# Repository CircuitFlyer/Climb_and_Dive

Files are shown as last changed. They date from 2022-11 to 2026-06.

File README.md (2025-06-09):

# Climb_and_Dive

## An Open Source Advanced Control Line Timer Project

Climb and Dive is an open source DIY project to create your own advanced timer for an electric powered control line model aircraft.  How advanced?  How about an active, governor timer with wireless programming!  Utilizing an inexpensive microcontroller development board in conjunction with an add-on circuitboard the timer is compact, light-weight and very simple to make and use.   Without opening any hatches or disconnecting any plugs the timer can be quickly programmed at the flying field using a Bluetooth application on your smartphone.  Because it’s open source, you can customize the functionality to your liking or even add new features.

## Project Philosophy

This project is a progression of the original basic Touch and Go timer.  I wanted to combine all of the positive features of other timers into one compact unit.  The target user group for this timer is first time beginners to novice flyers all the way up to more advanced stunt flyers.  It's still intended to adhere to the basic KISS principle; minimal components, built-in safety features and simple to make and operate without overly complex programming requirements.  I also wanted it to be easy as possible to change settings at the field without having to purchase or use any other attachments.

## Instructions

All of the assembly, programming and operating instructions can be found in the instruction manual on the document pages, [www.circuitflyer.com](https://circuitflyer.com/Climb_and_Dive/)  The program files can be downloaded from within the web pages or from the release tab above.

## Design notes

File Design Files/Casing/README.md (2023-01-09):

---
nav_exclude: true
---

# 3D Printed Enclosure for the Climb_and_Dive timer

Download the .stl files above to print a casing to house a complete timer assembly.  The casing is not completely weather tight but should add a layer of protection.

Assemble the top and bottom using (4) M2 x 10 machine screws.

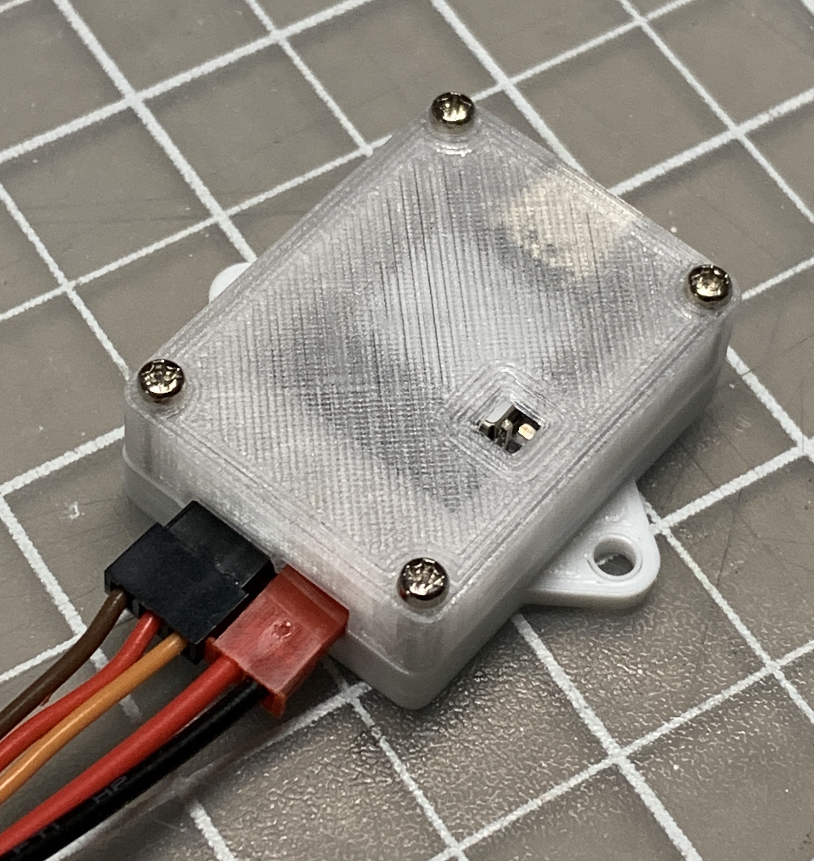
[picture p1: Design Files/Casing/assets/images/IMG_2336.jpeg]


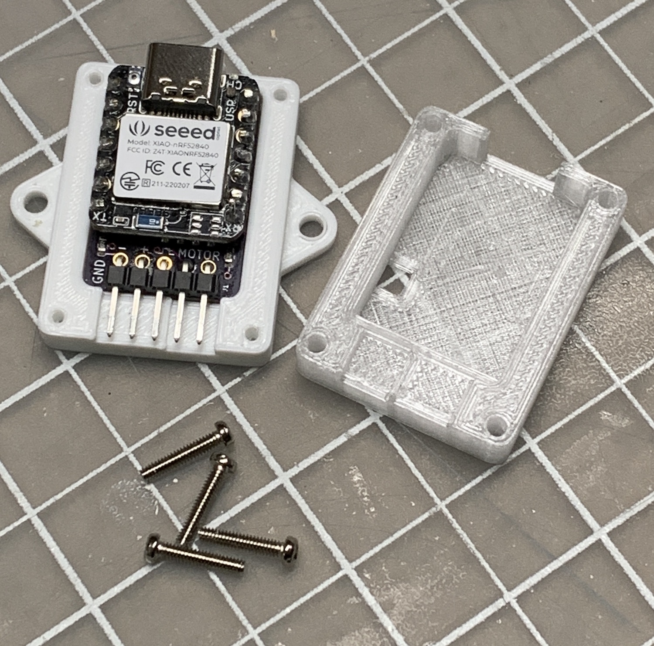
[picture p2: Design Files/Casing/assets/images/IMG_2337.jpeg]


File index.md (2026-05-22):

---
title: Home
layout: home
nav_order: 1
---

{% include Header.html %}
<br>
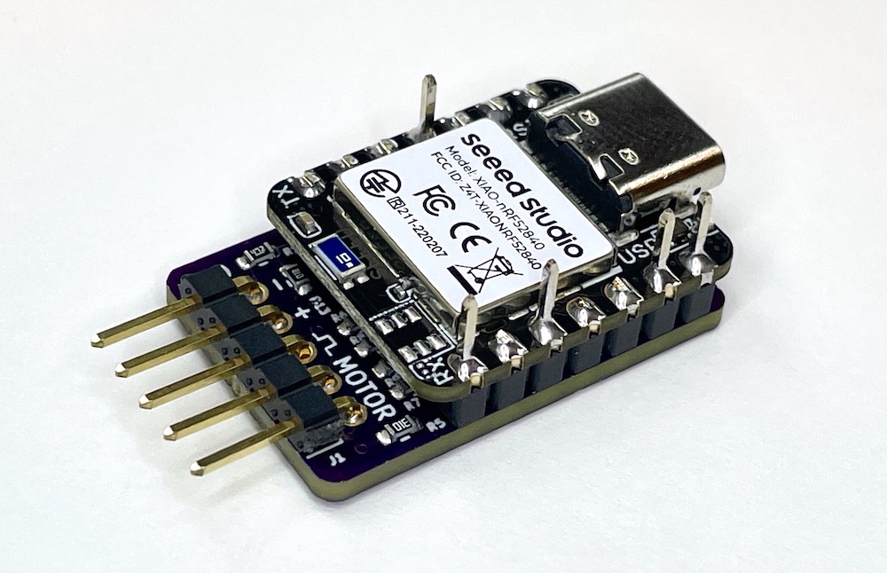
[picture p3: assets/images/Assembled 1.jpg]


# Revolutionary Active Control for Electric Control Line Flying!
{: .text-center }

## What It Is
Climb_and_Dive is an open-source, do-it-yourself project that lets you build an advanced timer for electric-powered control line model aircraft. The Climb_and_Dive timer isn't just a simple switch - it's an intelligent flight control system that **actively monitors and responds** to your aircraft's flight conditions in real-time. This compact timer combines a low-cost microcontroller development board with a custom add-on circuit board to deliver professional features in a simple, user-friendly package.

## Unique Capabilities
The Climb_and_Dive timer stands out as both an **active timer** and a **governing timer** in one device. What makes it truly innovative is its **wireless programming capability** through Bluetooth and your smartphone. This eliminates the hassle of opening hatches, dealing with connectors, or using separate programming boxes.

The program code includes **built-in safety features** that provide an additional layer of protection for your power system, helping prevent damage if something unexpected occurs during operation.

Since it's open source, you have complete freedom to customize the functionality or add new features to suit your specific needs.

## Simple Assembly
The timer comes as a DIY kit that requires minimal assembly—just soldering some header pins. The kit includes two main components:

- **Seeed Studio Xiao NRF52840 development board** (the main microcontroller)
- **Custom backpack circuit board** (contains the accelerometer and RPM signal conditioning circuitry)

The backpack design streamlines wiring and makes assembly fast and straightforward.

### GREAT NEWS! **- I now also offer an easy to install remote mounted user interface.  Add a remote pushbutton start switch and a super-bright status indicator LED to your timer.  Check out all the details <a href="https://circuitflyer.com/Control_Panel/" target="_blank" rel="noopener noreferrer">HERE </a>**

## Easy Programming and Updates
Programming the microcontroller is incredibly simple—just drag and drop a few files on your computer. The microcontroller comes pre-programmed and tested, so you can start using it immediately.

As new features are released, you can easily [update your timer's code](docs/Software#software-installation) using the same simple drag-and-drop process, ensuring your device stays current with the latest improvements and capabilities.
<br> <br>

<span class="fs-6">
[Click Here to order a **Climb_and_Dive** kit on **Lectronz**](https://lectronz.com/products/climb_and_dive){: .btn .btn-green}
</span>

## Extensive List of Features ##

- Dimensions: 27mm x 18mm x 9mm.  Weight: 5g.  Ideal for mounting on the side of a profile fuselage.

- An onboard accelerometer provides a programmable automatic boost in power during a climb as well as a seperate programmable decrease in power while in a dive.

- RPM throughout the flight is actively monitored and controlled by sensing the motor voltage using a feedback control loop.  No need for a tachometer.  No guesswork.  The RPM you set is the RPM you get.

- Works with lower cost ESC’s.  The governing function takes place in the timer so expensive governing ESC’s are not required.

- Wireless programming in the field via a *free* Bluetooth app using a laptop, tablet or smart phone. The start-up delay, flight time and governed RPM settings plus a lot more can be changed without any extra tools, cards or programming boxes.

- Touch sensitive pin for user input.  No additional switches or buttons to wire and mount.  If desired, the program code does provide for an optional remote push-button switch.

- Onboard multicolour LED to indicate the status of the timer.

- Functionality to add an optional remote mounted super bright Neopixel LED so the pilot can monitor the status indicator from the centre of the circle.

- The ability to improve overhead line tension by increasing the motor RPM only when flying high overhead.

- Programmable extra RPM boost in the bottom sharp corners of stunt maneuvers.

- Innovative pilot operated **emergency stop feature**.  3 quick pulls on the control handle will stop the flight so you can safely land the airplane at any time.

- Programmable soft start.  The RPM increases over a programmable time period for smoother take-offs.

- A 3 second boost in RPM at the conclusion of a flight to improve the landing glide or as a warning to indicate the impending end of the flight.

- Following a simple programming & calibration procedure the timer can be mounted in any orientation in the airplane.

- Power to the motor is cut off quickly and automatically if the propeller inadvertently strikes the ground.  No more burned out motors or ESC’s from a crash or nose-over on takeoff.

- Auto shutdown with a loss of power or a loss of motor RPM signal.

- Auto shutdown if motor fails to reach programmed RPM on takeoff.

- Should an auto shutdown occur, the onboard LED will flash a sequence of fault codes to aid in troubleshooting.

- Built-in micro USB C port.  Plug it into your computer and it shows up as a small disk drive.   This makes it very easy to keep the software up to date with the latest revisions.

- The program code is written in Adafruit CircuitPython.  CircuitPython is an easy to read and easy to learn language well supported by comprehensive [learning guides on the Adafruit website][1].

- Reprogrammable.  Have another project idea in mind?  The Xiao line of development boards have the same footprint and pinouts as the Adafruit QTPy size of boards.  The Climb_and_Dive hardware platform is also a great starting point to use in developing code for your own project.  The Xiao can also be programmed as an [Arduino device][2] if you prefer.

<style>
  .responsive-iframe {
    width: 100%;            /* Fill the width of its container */
    max-width: 800px;       /* Optional: stop it from getting too big */
    aspect-ratio: 4 / 3;   /* Keeps it in desired format */
    border: none;
  }
</style>

<iframe class="responsive-iframe" src="https://www.google.com/maps/d/u/1/embed?mid=1vEqo7SIi-lv9DnAQE8pMjQOn-hjqEW4&ehbc=2E312F&noprof=1"></iframe>

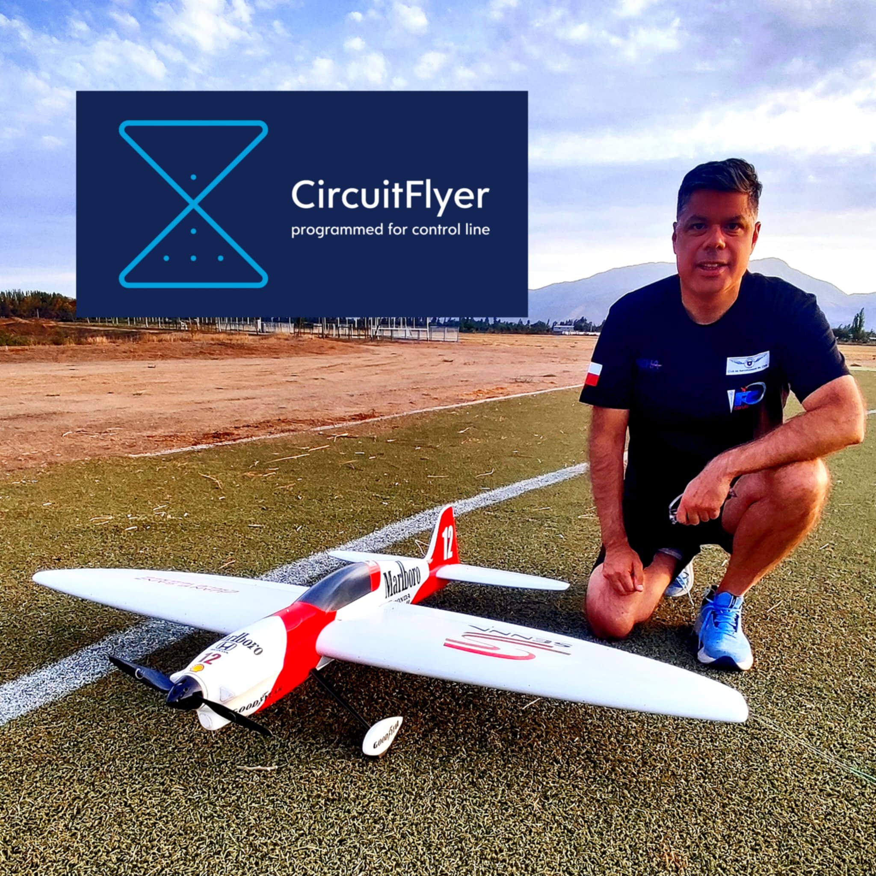
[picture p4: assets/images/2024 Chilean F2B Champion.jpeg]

Congratulations to Juan Francisco Sainz Valencia, 2024 & 2025 Chilean F2B Champion and Climb_and_Dive timer advocate.

[1]: https://learn.adafruit.com/
[2]: https://wiki.seeedstudio.com/XIAO_BLE/

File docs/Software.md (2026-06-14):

---
title: Software
layout: default
nav_order: 4
---

{% include Header.html %}

## Software Installation ##

One of the great features of the Climb_and_Dive timer is the ability to update the program code as new features and improvements become available.

**Note:** All Xiao NRF52840 microcontroller boards supplied through the Lectronz shop are shipped ready to assemble with the latest timer program already installed and tested.  Software installation is not required and you can skip ahead to the Bluetooth app installation.

The instructions below cover two separate procedures.  The first procedure is used for a quick update to the existing program code when a newer version is released.  The second procedure is used for a more in-depth update or if you purchased a blank Xiao microcontroller board from another source.

{: .highlight}
Be sure to check here from time to time to make sure you are using the most up to date version of the program code.  **Latest Version: v1.5.3**  Note: if upgrading from a previous version it is always a good idea to update both **code.py** AND the **lib** folder (Step 6 below).  See the **README** included in the download for details.

<span class="fs-6">
[Click Here to download the latest program code .zip file](https://github.com/CircuitFlyer/Climb_and_Dive/archive/v1.5.3.zip){: .btn .btn-blue }
</span>

The current version installed on your timer is shown in the name of the device that appears when you connect to it via the Bluetooth app.

### Quick Update of the Software: ###

If there is a newer release of the program code, use the following procedure to overwrite and replace only the one file called **code.py** on your timer.  (Occasionally, additional files may also need to be updated.  See the README included in the download for details.)

First, a bit of background on how CircuitPython works: Whenever the timer is powered up, CircuitPython looks for a file called **code.py**, loads it into the memory and automatically begins to run the program.  The file name must be **code.py**.  Do not rename the file for or use any other file name for the program code.  This may cause confusion as both the previous version and the newest version will have the same file name.  Hence the requirement to overwrite and replace the old version with the new version, do **not** keep both.

**Step 1** - Download the .zip file from the link above.  Unzip the download and have a look inside.  You will see several different items listed there.  You are only interested in the file named **code** that has a file extension of **.py** (the python programming language file type).

**Step 2** - Connect the timer to your computer using a USB type C cable.  The timer will power up and a new removable drive called `CIRCUITPY` will appear on your computer.

{: .highlight }
A quick note about USB C cables: If you have trouble getting the disk drive to show up on your computer there is a possibility you are not using a data cable.  There may be some USB cables that are used for charging only and are not data transfer cables.  Be sure you have the right one.

**Step 3** - Drag and drop the **code.py** file from the latest download onto the `CIRCUITPY drive`. Your computer will tell you that a file with the same name is already on the drive and ask if you want to replace the file or keep both. Click **Replace**, do **not** keep both.



Give it a second while the latest version of the program code overwrites the old file.  The timer will re-start and automatically begin running the new code.  That’s it, you’re all done.  

**Step 4** - Eject the `CIRCUITPY` drive and unplug the USB cable from the timer

### In-depth Update and New Installation of CircuitPython: ###

There are two reasons why you would need to use the following procedure:

1) If you purchased a blank Xiao NRF52840 from another source you will have to perform a new installation of CircuitPython along with all of the program files and libraries.

2) Adafruit has released a new and improved version of CircuitPython. Eventually there will be a requirement to perform a more in-depth update to use the latest CircuitPython and overwrite all of the program files and libraries on your timer with the newest versions.

**Step 1** - Download the .zip file from the link above.  Unzip the download and have a look inside.  You will see several different items listed there.

**Step 2** - Connect the timer to your computer using a USB type C cable.  If you have a new blank Xiao NRF52840, nothing will happen. Don't worry, that's normal for a board that doesn't have CircuitPython installed yet.  If you are updating your existing timer a new removable drive called `CIRCUITPY` will appear on your computer.

**Step 3** - Enter Bootloader mode<br>

Before we install CircuitPython to the Seeed Studio XIAO nRF52840, it needs to be in bootloader mode. Enter the bootloader mode by clicking the very tiny Reset Button **twice**:

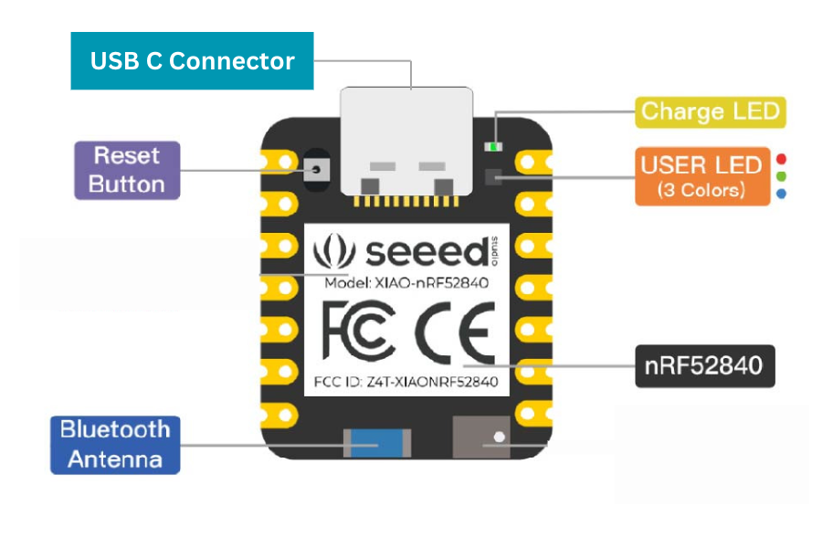
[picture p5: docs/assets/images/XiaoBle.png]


Give it a couple of seconds, then the `XAIO-SENSE` disk drive will show up:



**Step 4** - Drag the **CircuitPython .uf2** file that you downloaded and drop it onto the `XAIO-SENSE` drive.<br>



**Step 5** - After 15 seconds or so, the disk drive will automatically exit bootloader mode and the name will change to `CIRCUITPY`.



Congratulations, you have successfully installed CircuitPython.  

Next, install the Program Code and Library Files:

**Step 6** - Drag the complete **lib** folder that you downloaded and drop it onto the `CIRCUITPY` drive.  Your computer may ask if you want to replace the folder on the drive. Click **Replace**, don't keep the old one.  Next, drag and drop the **code.py** file onto the `CIRCUITPY` drive.  Again, **Replace** any existing versions.



Congratulations, you should now have an up to date Climb_and_Drive timer.  The LED on the Xiao should illuminate green to indicate that it's currently in Standby mode.

**Step 7** - Eject the `CIRCUITPY` drive and unplug the USB cable from the timer

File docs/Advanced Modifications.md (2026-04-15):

---
title: Advanced Modifications
layout: default
nav_order: 8
---

{% include Header.html %}

## Advanced Modifications ##

**Overview**

To a limited extent, the Climb_and_Dive timer can be further customised to suit your particular requirements.  This section covers some of the modifications available.

These modifications are considered more advanced and are **not** required for normal operation of the timer.  They should only be considered if you have some previous electronics and/or programming experience, are confident in your abilities and have a basic  understanding of microcontroller development boards.  Care must be used with any wiring modifications to the timer to prevent permanent damage to the microcontroller.

If you wish to learn more before diving in, both [Adafruit][1] and [Sparkfun][2] can provide the supplies and equipment for experimenting and learning.   On the surface, both of these companies appear to be retailers of electronic devices for the maker community.  In reality they are best described as companies with a primary goal of education.  To that end, they encourage experimentation by offering beginner orientated electronic products along with comprehensive online learning tutorials.

**Pinouts**

Here is the official Seed Xiao NRF52840 microcontroller board pinout diagram:

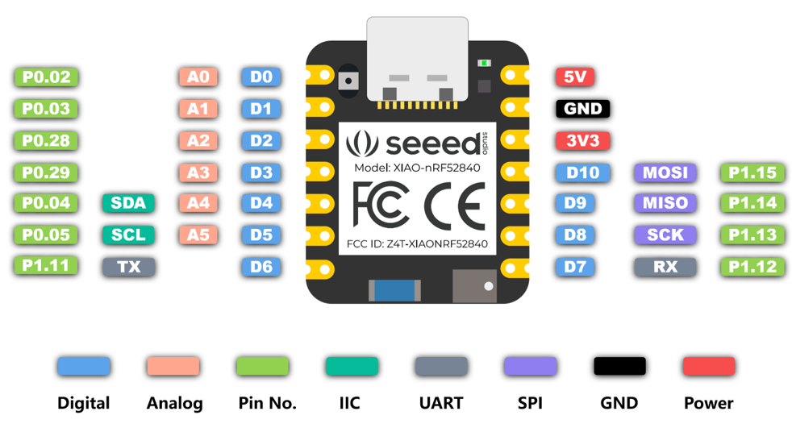
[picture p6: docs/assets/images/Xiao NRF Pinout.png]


As you can see each GPIO pin can be configured for use in a number of different ways.  

{: .warning }
Be careful to never short the power pins to ground.  The 5V pin can only provide a maximum of 1A.  The 3V3 (3.3 volt) pin may be able to supply up to 100mA current.  The same caution applies to any pins configured as outputs.  The GPIO pins can only source and sink a very tiny amount of current, not even enough to directly power a single LED.  Always protect any exposed solder pins with heat shrink tubing to help prevent accidental short circuits.

<br>

**Remote Addressable LED Indicator**

### NEW! **- As an accessory product, I now also offer an easy to install remote mounted user interface.  It combines a remote pushbutton start switch and a super-bright status indicator LED pre-soldered to a printed circuit board ready to install on your airplane.  Check out all the details <a href="https://circuitflyer.com/Control_Panel/" target="_blank" rel="noopener noreferrer">HERE </a>**
<br>

The following information is provided if you would like to customise your installation and wire your own super-bright status LED to the timer.  

NeoPixel is the name Adafruit uses to describe WS2812 addressable LEDs.  These are unique RGB LEDs with an integral control circuit inside.  They are **not** your typical 3 colour LED with a common anode/cathode.  The traditional 3-colour LEDs will not work with the timer.

NeoPixels have 4 connections; +5V, Ground, Data In and Data Out.  They are available in several different types and sizes of packages.  For this modification I suggest the diffused, 5mm diameter, through hole type NeoPixel.  A package of (5) NeoPixels be purchased from [Adafruit - 5mm Diffused][3] or [Sparkfun - 5mm Clear][4] as well as through other online retailers.  If you purchase LEDs from another retailer you must refer to the supplier documentation for the LED as other manufacturers use different pin assignments, there is no industry standard pinout.

Although you can wire the NeoPixel directly to the timer, it’s probably a good idea to attach it using a removable connector.  One suggestion is to use a JST-PH 2.0 3-pin connector.  This type of connector will always ensure proper polarity when connecting thing up.  Both [Adafruit - Cable Matching Pair][5] and [Sparkfun - Jumper Assembly][6] have some available.  It is advisable to keep the wire length as short as possible for your particular installation.

The Adafruit 5mm through hole NeoPixel connections:

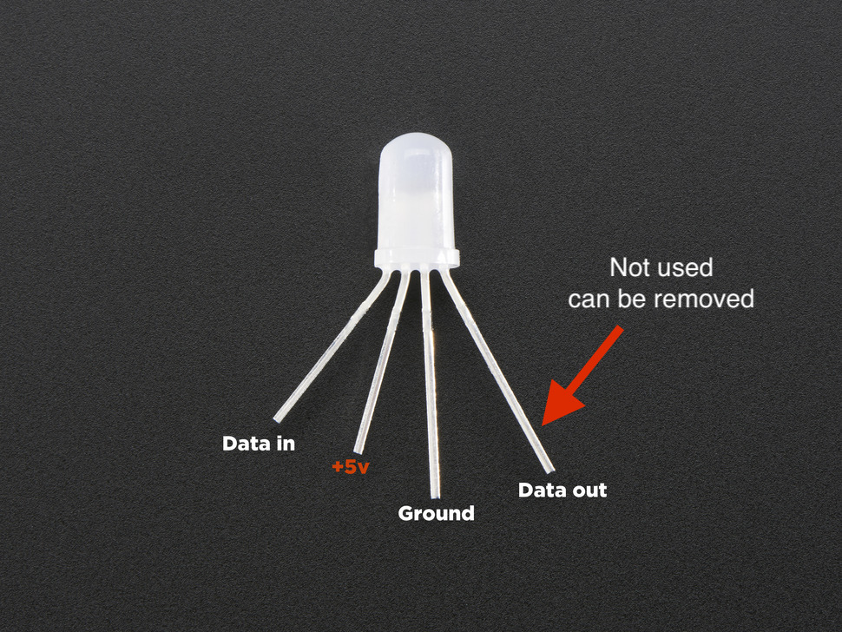
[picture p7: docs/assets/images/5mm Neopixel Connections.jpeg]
  

Note the two short wires and two long wires.  the Data Out wire will not be used and can be trimmed off.  The connections required are fairly straightforward; 5V to +5V, GND to Ground and Data In to Xiao Pin A3/D3.  The wire colours supplied with your connector may be different from the ones shown here.  Double check for correct wiring before applying power for the first time.

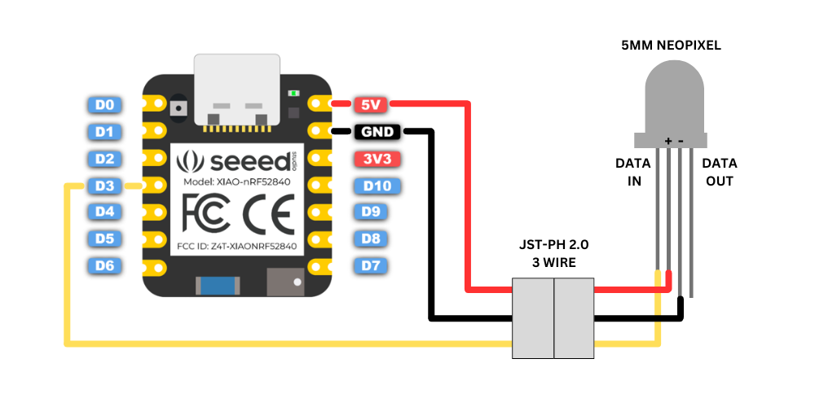
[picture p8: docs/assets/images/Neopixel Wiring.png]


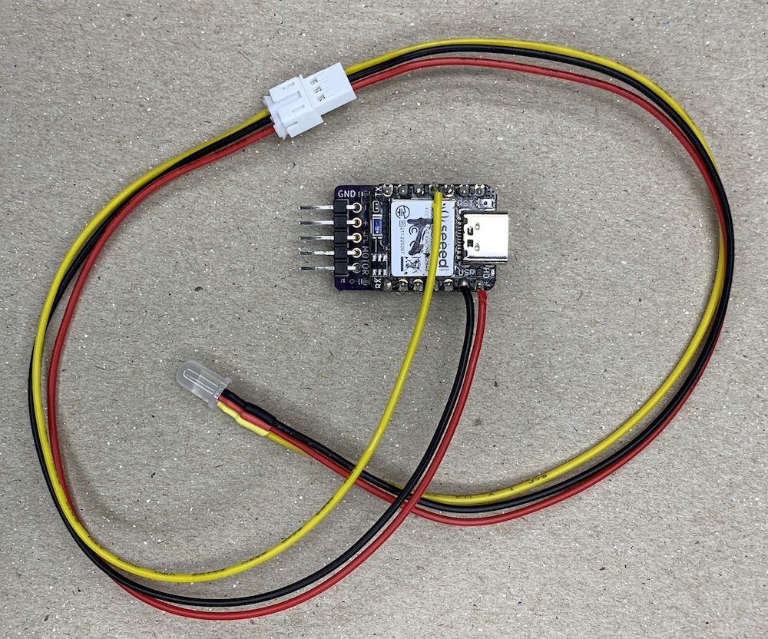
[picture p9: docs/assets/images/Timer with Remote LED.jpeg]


{: .highlight }
The NeoPixel connections described above are not necessarily the ideal recommended connection circuitry but, it has been tested and works well in this particular case.

Note 1: If you would like to use a different Neopixel or WS2812 LED other than the one suggested above, you may have to change the **pixel_colour** in the program code for it to illuminate the correct colours.  See below for details.

Note 2: If you are also using the optional push-button start switch then there will be (2) wires connected to the ground pin (GND).  That is permissible as both the Neopixel and the switch share a common ground circuit.

<br>

### Additional Parameters Accessible within the Program Code ###
<br>
For users that might like to modify some of the other settings written into the code I have specifically listed a few variables near the top of the code for easy access.  These variables can be changed from the default values and then saved back onto the timer using a simple text editor program on your computer.

Connect the timer to your computer using an appropriate USB data cable.  A removable drive called CIRCUITPY should appear.  Inside the drive you will find the timer program file named code.py.  Right click on the file name and select ‘Open With’ from the menu that appears.  On Mac computers, select ‘TextEdit’ to open and edit the code.py file.  On Windows computers, select ‘Notepad’ to open and edit the file.

With the file open scroll down a little until you see the list of parameters that can be customized.  Note: Do not alter the formatted structure of the program or change the names of any variables.  Only change the value assigned to each named variable.  Once you have assigned a new value simply ‘Save’ the file.  The code.py file will be written back onto the timer and the code will automatically restart and use the new value you assigned.

If you make an error, download a new copy of the latest timer code package and overwrite your copy of code.py with the new one.  Note: Please keep a record of the parameter values that you changed.  When a new code release is published you will need to go back in and change the customizable variable values again.

{: .highlight }
CircuitPython Programming 101: numerical values can be entered as integers (whole numbers) or as floats (numbers with decimal fractions).  CircuitPython automatically uses the correct type.  Text values, commonly called text strings, must always be entered between “ “ double quotation marks.  CircuitPython uses the double quotation marks to denote a text string data type.  All other punctuation marks, including spaces, are permissible and can be used between the double quotation marks.

The following table summarizes the variables available for modification:

| Variable Name | Default Value | Description |
| --- | :---: | :---: |
| blip_duration | 0.5 | Length of start-up throttle blip |
| blip_RPM | 1150 | PWM throttle setting for start-up blip |
| touch_pin_sensitivity | 100 | Sensitivity level of touch sensor |
| timer_name | “Climb & Dive vX.X” | Name displayed on Bluetooth app |
| pixel_colour | “RGB” | Order of coloured pixels |
| glide_boost | 3 | Length of high RPM at end of flight |
| corner_boost_duration | 0.6 | Length of corner boost |

**Detailed Description, Restrictions and Warnings**

**blip_duration** - This is the short length of time, in seconds, that the motor operates to indicate the start of the timer sequence.  You can enter smaller or larger values if you prefer.  Too short and your ESC might not move the prop at all.<br>
**blip_RPM** - This is the PWM pulse width throttle setting, in microseconds, sent to the ESC during the start-up blip.  If you would like to adjust this value to speed up or slow down the motor I would suggest experimenting in 25 or 50 microsecond steps.  This is very dependant on the ESC used.  If this value is set below the minimum endpoint value the prop will not move at all.<br>
**touch_pin_sensitivity** - This is an arbitrary number that you can use to adjust the sensitivity of the touch pin.  Be careful using values below 30 as it may become very sensitive and easy to trigger accidentally.<br>
**timer_name** - If you have several timers you may like to change the name displayed on the Bluetooth app when you connect.  **Warning: the maximum number of characters (including spaces and punctuation) is limited to 26.**  If you exceed that the program code will throw an error and stop.  You may have to connect to your phone at least one time in order to see the change.<br>
**pixel_colour** - Neopixels come in different flavours.  Some have a pixel order of red-green-blue, "RGB", and others are green-red-blue, "GRB".  This is where you can change the pixel order in case the Neopixel you choose has the red and green colours inverted.<br>
**glide_boost** - This is the length of time, in seconds, that the motor runs at a higher RPM at the end of the flight sequence.  You may prefer to increase or decrease this time.<br>
**corner_boost_duration** - This is the length of time, in seconds, that the motor operates at the higher programmed RPM after the timer identifies a sharp corner.

[1]: https://www.adafruit.com/
[2]: https://www.sparkfun.com/
[3]: https://www.adafruit.com/product/1938
[4]: https://www.sparkfun.com/products/12999
[5]: https://www.adafruit.com/product/5087
[6]: https://www.sparkfun.com/products/9915

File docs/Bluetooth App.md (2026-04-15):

---
title: Bluetooth App
layout: default
nav_order: 5
---

{% include Header.html %}

## Bluetooth App Installation ##

The preferred Bluetooth app is called ***Bluefruit Connect*** published by Adafruit industries and is available as a free download from both [Android Google Play][2] or from the [Apple App Store][1].  Adafruit publishes this app as a generic Bluetooth, or BLE (Bluetooth Low Energy), development tool for programmers and hobbyists to experiment with the various Bluetooth enabled development boards that they offer.

{: .highlight }
**Update:** April, 2026 - Attention iPhone users: Once you become familiar with the Bluefruit Connect app, I found a suggested alternative app called [**BLESerial nRF**][4] that you may like to try.  Sorry, it's not available for Android users.

The Bluefruit Connect app is capable of several different tasks.  Communication with the Climb_and_Dive timer only requires the use of the UART Service.  UART is a standardized communications protocol used to transfer data between different devices.  Pairing is not required.

Download and install the Bluefruit Connect app.  Open the app and set it up as shown below.
- Show unnamed devices **OFF**
- Must have UART Service **ON**
- Multiple UART mode **OFF**

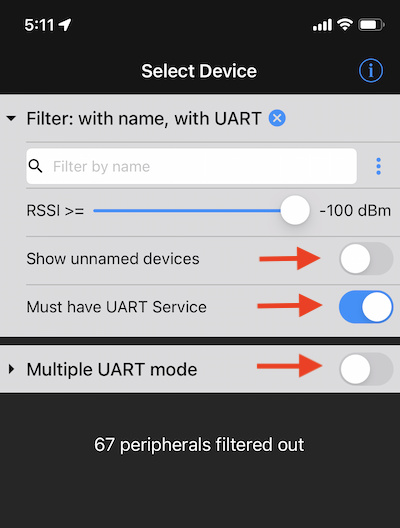
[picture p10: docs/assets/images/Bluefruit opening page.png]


Using the app with the timer is covered in the programming section of the operating instructions.  If you have a questions or would like to learn more about the app, Adafruit has detailed tutorial [here][3].

[1]: https://apps.apple.com/ca/app/bluefruit-connect/id830125974
[2]: https://play.google.com/store/apps/details?id=com.adafruit.bluefruit.le.connect&hl=en_CA&gl=US&pli=1
[3]: https://learn.adafruit.com/bluefruit-le-connect/ios-setup
[4]: https://apps.apple.com/ca/app/bleserial-nrf/id1632235163

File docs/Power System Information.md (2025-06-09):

---
title: Power System Information
layout: default
nav_order: 6
---

{% include Header.html %}

## ESC Information ##

The details of how to program your ESC (electronic speed controller) is outside the scope of these instructions.  Please refer to your ESC instruction manual for information.  If you are completely new to how electric control line power systems work, a brief overview can be found [here][1].

As a reference guide, use the following table for suggested settings for ESC programming.

{: .highlight }
Note: The features described may or may *not* be present in the ESC you are using.

| ESC Programmable Feature | Recommended Setting |
| --- | :---: |
| RPM Governing | OFF |
| Brake setting | ON |
| Soft start | OFF |
| BEC Voltage Output | 5.0V or 5.5V Maximum |

{: .highlight }
Note: Castle Creations Phoenix ESC's are more intricate and discussed in greater detail [below](Power%20System%20Information.html#castle-creations).

The timer PWM signal covers a very wide throttle range and ESC throttle calibration is not likely required.  If you think your ESC requires throttle calibration and your instructions call for the RC transmitter stick to be at maximum throttle at power-up, use the following procedure:

**Step 1** - **Remove the propeller from the motor.**<br>
**Step 2** - Hold the timer touch pin while connecting the battery power.  The timer will start up and output a maximum throttle signal.<br>
**Step 3** - After the ESC is calibrated, release the timer touch pin.  The timer output will return to minimum throttle and the ESC should arm.<br>
**Step 4** - Disconnect the battery and re-install the propeller.

## Motor Information ##

In order for the timer to accurately determine the motor RPM you must know the number of magnetic poles used in your motor.  14 poles is the default choice but some motors use a different number.  The number of magnetic poles  can be found in you motor documentation or by counting the number of magnet segments glued around the inside of the rotating part of the motor.  Be sure ***not*** to count the number of stationary copper windings.

Please refer to the timer Bluetooth programming section for information on where to enter this information.

## Castle Creations ##

The Castle Creations Phoenix EDGE and TALON line of ESC's have additional complexity and warrant a separate discussion.  A Castle Link USB device and the associated software is required to upload the necessary adjustments to the ESC to make it compatible for use with the Climb_and_Dive timer.  Unfortunately, the older Castle Creations Phoenix ICE line of ESC's are not the best match for this timer.

The Throttle must be setup to use **Multi-Rotor** as the Vehicle Type.  Do *not* use Control Line as a Vehicle Type.  The governor function of the Climb_and_Dive *timer* must be allowed complete control of the throttle; free from any output delay or input filtering within the ESC.  The Airplane Vehicle Type is also *not* a viable option.  Primarily due to the lack of a procedure to match the ESC throttle range to the timers fixed outputs.  Both Helicopter and External Governor types do *not* have braking enabled.

The Brake should be set to 100%.  The amount of Brake Delay and Brake Ramp can be adjusted to suit your requirements.

Cutoffs are another setting that are subject to personal preferences.  The Cutoff Voltage (and/or Auto-Lipo Volts/Cell) may be set to values suggested by your battery manufacturer.  (Low) Voltage Cutoff Type is debatable.  When using a control line timer, the obvious choice is an immediate Hard Cutoff.  The Climb_and_Dive timer in use with a Phoenix ESC does allow choosing the Soft Cutoff option.  When the low voltage limit is reached using a Soft Cutoff the RPM will slowly decrease.  When the RPM decreases to 75% of the programmed flight RPM the timer will automatically shutdown. Pulse Cutoff and RPM Reduction Cutoff are *not* viable choices.

The Current Limiting value is your choice.  For Current Cutoff Type, Hard Cutoff is strongly suggested.

Motor Start Power is not that important for most control line models.  It has no bearing on the operation of the timer and can be set to your liking.  The other Motor settings are motor dependent and have very little influence on the operation of the timer.

BEC Voltage must be set to 5.0V.

[1]: https://circuitflyer.com/electric%20power%20system%20101.html

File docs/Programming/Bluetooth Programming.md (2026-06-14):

---
title: Bluetooth Programming
layout: default
parent: Operation
nav_order: 1
---

{% include Header.html %}

## Bluetooth Programming Instructions ##

### Settings ###

There are several features of the the timer that you can customize based on a user programmable setting.  Bluetooth 'pairing' is not required.

**Start Delay Time**<br>
The start delay is programmable from 0 to 60 seconds in 1 second intervals.  This is the time delay between when the timer flight sequence begins and when the motor starts up for take-off.  This gives the pilot time to walk to the handle and get ready before the motor starts.

**Flight Time**<br>
The flight time can be set from 1 second to 360 seconds (6 minutes) in 1 second intervals.  This time begins when the motor reaches full flight RPM and lasts until the 3 second period of increased RPM just before the motor stops at the end of the flight.

**Motor RPM**<br>
The governed RPM can be set from 5000 RPM to 15000 RPM in 10 RPM increments.  This setting is the base RPM (or setpoint) that the PID control loop inside the timer will use to control the ESC. This control loop will work to maintain a constant RPM throughout the flight even as the battery voltage decreases.

**Climb Gain**<br>
The climb gain is an arbitrary multiplier with a value from 0 through 10 (integer values only).  This number is used to multiply the output of the accelerometer reading and adds the results to the setpoint to increase the RPM slightly when the model is in a climb.  0 turns the accelerometer input off and a setting of 10 would be the maximum RPM boost possible.  Most pilots will likely use a setting between 4 and 6.

**Dive Gain**<br>
The dive gain is an arbitrary multiplier with a value from 0 through 10 (integer values only).  This number is used to multiply the output of the accelerometer reading and subtracts the results from the setpoint to decrease the RPM slightly when the model is in a dive.  0 turns the accelerometer input off and a setting of 10 would be the maximum braking effect possible.  Most pilots will likely use a setting between 4 and 6.

**Motor Acceleration**<br>
The motor acceleration is an arbitrary multiplier with a value from 1 through 10 (integer values only).  This number is used to adjust the amount of time that the motor takes to startup at take-off.   A setting of 1 is a very slow acceleration of the motor RPM and a setting of 10 is a very quick startup.

**Number of Motor Poles**<br>
Enter the number of magnetic poles used in your motor.  The timer needs this information in order to accurately calculate the RPM.  The number of magnetic poles  can be found in you motor documentation or by counting the number of magnet segments glued around the inside of the rotating part of the motor.

**Last Lap Time**<br>
Enter the amount of time from 0 to 10 seconds that you would like the motor to run at normal speed *after* the short burst of high RPM at the end of the flight.  If you prefer to use the short burst of high RPM to set-up for a better landing glide, set this time to 0.  If you prefer the use the short burst of high RPM as a warning signal to indicate the end of the flight, enter a length of time that allows you prepare for landing.

**Mounting Position & Calibration**<br>
This option is required and must be completed prior to using the Corner Boost feature described below. For further information and details of the programming procedure, please refer to the page titled [Timer Mounting Position & Calibration](Timer Mounting Position & Calibration).

**Overhead Boost**<br>
The overhead boost setting is an arbitrary multiplier with a value from 0 through 10 (integer values only).  This number is used to adjust the amount of extra motor RPM that is added when flying high overhead.  0 turns the feature off and a setting of 10 would give the maximum boost in RPM when flying overhead.  Most pilots will likely use a setting between 4 and 6.

**Corner Boost Gain**<br>
The corner boost setting is an arbitrary multiplier with a value of 0 thru 10 (integer values only).  This number is used to adjust the amount of extra motor RPM that is added when flying the lower altitude sharp corners required for certain aerobatic maneuvers.  A sharp turn can slow the airplane down.  Adding an extra boost of power in the turn can help maintain airspeed.  0 turns the feature off and a setting of 10 would give the maximum boost in RPM during a sharp turn.  Most pilots will likely use a setting of 4 or 5. **Note:** this feature is only available after the [Timer Mounting Position & Calibration](Timer Mounting Position & Calibration) procedure has been completed.

**E-Stop**<br>
The emergency stop feature can be used to end the flight before the normal programmed flight time is complete.  This feature has three settings; OFF, TEST and ON.  For the complete details on how it is activated and used please see the page entitled [Emergency Stop](Emergency Stop).

The table below summarizes the programmable settings available and their default values:

| Programmable Setting | Allowable Range | Default Setting |
| --- | :---: | :---: |
| Start Delay Time | 0 to 60 | 10 Seconds |
| Flight Time | 1 to 360 | 180 Seconds |
| Motor RPM | 4000 to 15000 | 10000 |
| Climb Gain | 0 to 10 | 5 |
| Dive Gain | 0 to 10 | 5 |
| Motor Acceleration | 1 to 10 | 5 |
| Number of Motor Poles | 2 to 28 | 14 |
| Last Lap Time | 0 to 10 | 0 |
| Mounting Position| - | +Z, -X |
| & Calibration| - | 0.0, 0.0 |
| Overhead Boost | 0 to 10 | 5 |
| Corner Boost| 0 to 10 | 0 |
| E-Stop | OFF, TEST, ON | OFF |

<br>

### Programming the Timer ###

**Step 1** - Connect the battery and boot up the timer.

**Step 2** - Tap your finger on the touch pin 5 times. The LED should turn a steady yellow (Programming mode, or more specifically Program Start Delay mode).

**Step 3** - Open the Bluefruit Connect app on your phone. Give it a second to search for the timer and the Climb & Dive timer should show up.

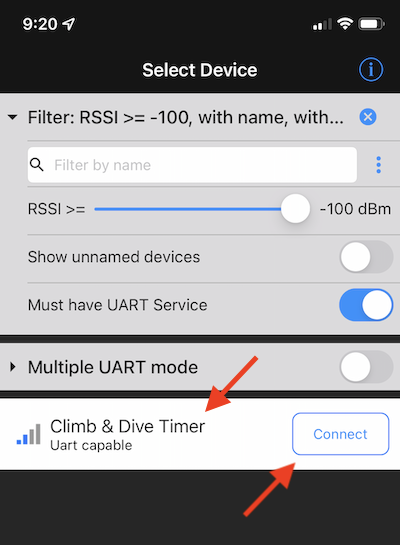
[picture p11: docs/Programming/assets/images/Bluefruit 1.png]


**Step 4** - Press the **Connect** button.  After a connection is established, the next page will automatically open to display the modules available.  Once connected the timer LED will change to a steady blue (BLE Program mode)

**Step 5** - Select the **UART** module.

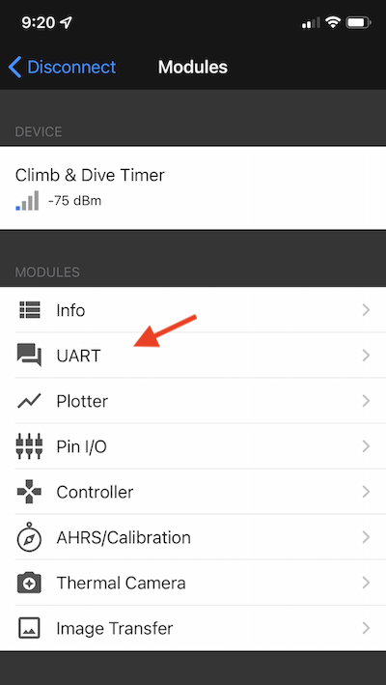
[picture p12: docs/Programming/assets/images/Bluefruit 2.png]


The UART module will open but the screen will be blank.

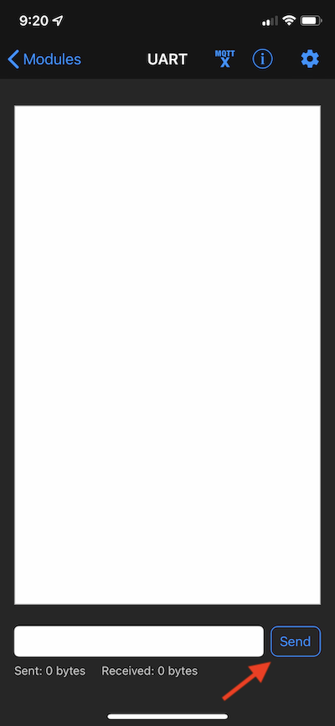
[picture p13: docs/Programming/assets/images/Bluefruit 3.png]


**Step 6** - Tell the timer that you now have the screen open by hitting the **Send** button once.  The timer will respond and list all of the current settings.

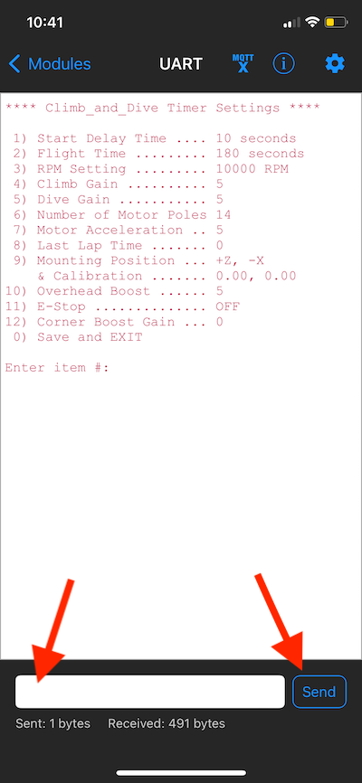
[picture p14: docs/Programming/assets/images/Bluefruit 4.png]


<details markdown="block">

<summary> Click here if your page doesn't look like the one above.</summary>

Your Bluefruit Connect UART page may look different if you may have the Display Mode set to Timestamp and not Text.

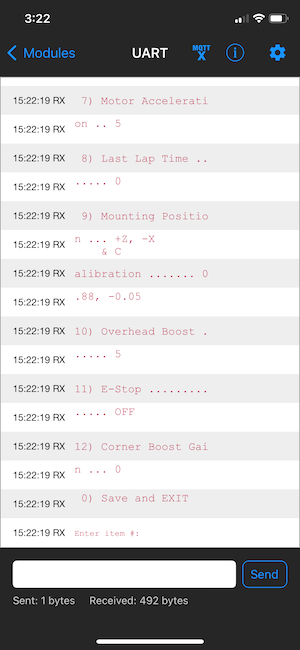
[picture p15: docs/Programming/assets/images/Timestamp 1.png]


Under the gear shaped icon in the top righthand corner you will find the drop-down menu to change the Display Mode.

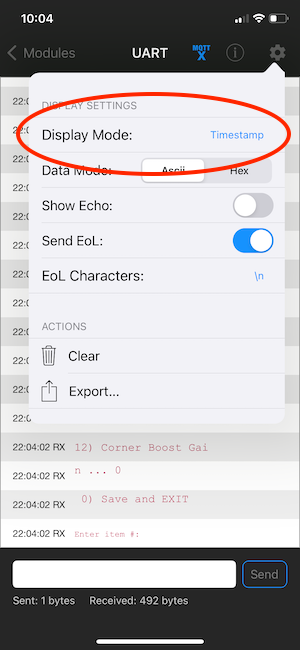
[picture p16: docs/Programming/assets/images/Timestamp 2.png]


Change the Display Mode to **Text**.

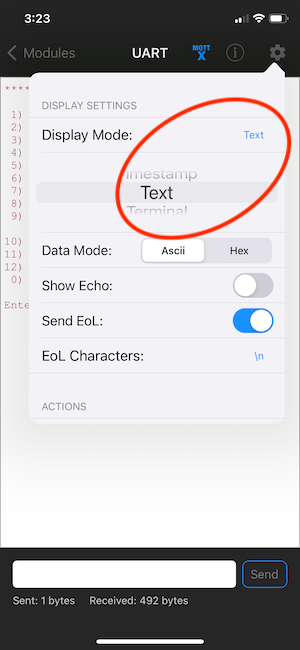
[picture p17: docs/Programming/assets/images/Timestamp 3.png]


Close the menu and now your page will be less cluttered without the timestamp information.

Moving on:

</details>

**Step 7** - Enter the *item number* of the setting you would like to change into the text box then hit **Send**.  The timer will then show the current setting and ask for the new one.

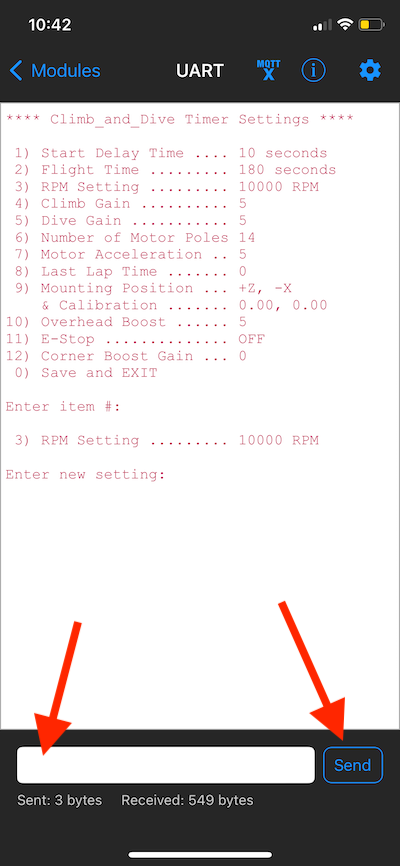
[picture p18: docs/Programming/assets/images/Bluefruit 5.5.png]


**Step 8** - Enter the new setting you would like to use and press **Send**.  The timer will then list all of the parameters again including the one you just changed.

Repeat steps 7 and 8 for any other settings you would like to change.  

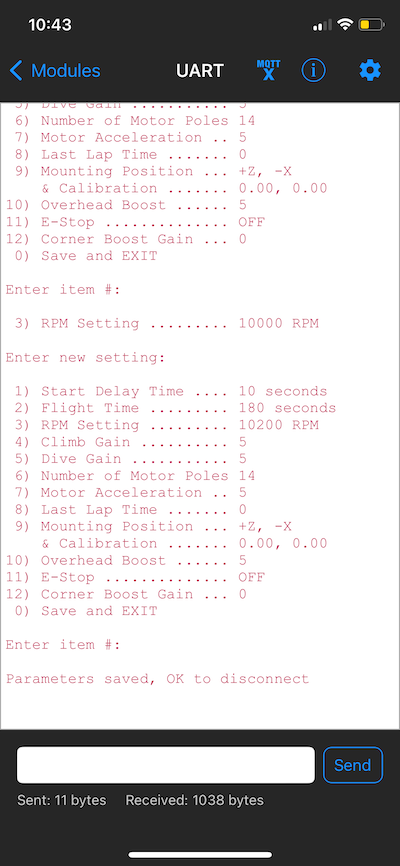
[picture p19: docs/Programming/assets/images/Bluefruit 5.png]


**Step 9** - When you are finished enter ***item number 0*** to save the settings and disconnect.  The timer LED will change to green (Standby mode).

**Step 10** - Tap on the **Modules** button in the top left of the screen to return to the Modules page.  Then tap on the **Disconnect** button in the top left again to return to the opening screen.  On the app main screen it is now safe to hit the **OK** button to disconnect and then close the app.

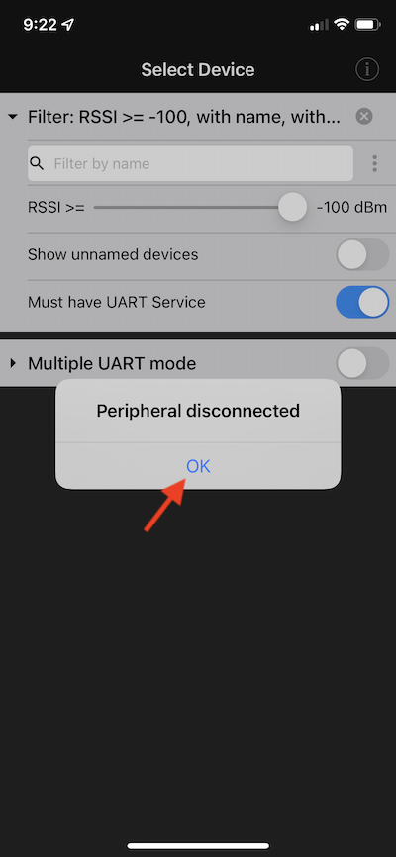
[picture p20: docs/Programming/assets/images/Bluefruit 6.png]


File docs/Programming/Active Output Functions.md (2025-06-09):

---
title: Active Output Functions
layout: default
parent: Operation
nav_order: 4
---

{% include Header.html %}

## Active Output Functions ##

The use of an electronic aid to actively control the motor RPM during flight can be a very useful feature. The general idea behind the active function is to assist the aircraft to try and maintain a more constant velocity throughout the entire flight.  The timer can boost the motor RPM in a climb and reduce it in a dive. It can also add RPM when flying high overhead to get a little more line tension when needed.  The design intent of the Climb_and_Dive timer is to keep the integration of the active function simple to use and easy to understand.

{: .highlight}
**Note:** An important requirement of the Climb_and_Dive timer is to avoid starting any stunt maneuvers until after the completion of 2-3 laps of normal level flight after take-off. There are a couple of reasons for this requirement:<br><br>
**1)** The active output is suppressed for the first 5 seconds after take-off. This is necessary in order to allow the aircraft unhindered acceleration to reach a stable cruising speed. Therefore, **do not hold the running airplane for extended periods before releasing for take-off.**<br><br>
**2)** For the time period between 5 seconds and 10 seconds after take-off, the timer is collecting accelerometer readings for use in a self correction procedure. Approximately one full lap of data collection is needed to account for different wind conditions. This self correction takes place each flight and allows changing lap times (different propellers, motor RPM or line length) without having to go back and alter any active function settings.

A good practice to follow is to turn off all active output aids while test flying and trimming a brand new airplane. Set the Climb Gain, Dive Gain, Overhead Boost and Corner Boost values to 0.  In this configuration the timer acts as a governing timer only.  The RPM will be held constant at the programmed setpoint throughout the entire flight.  After following the standard trimming procedures to achieve the best flying airplane, then it’s time to start to experiment and incrementally add the active outputs as desired.

Climb Gain is used to boost the RPM when the airplane is increasing in altitude.  The output of the active function is proportional to the rate of change in altitude.  For example, in a wingover the boost comes on gradually and the maximum RPM due to the Climb Gain will occur around 45º and then taper off as it reaches the top of the hemisphere.

Dive Gain works in a similar manner with the RPM starting to decrease from the setpoint as it goes over the top and then reaches the maximum decrease in RPM at the exit of the maneuver.

The Overhead Boost function is used to add extra RPM when flying overhead.  It will gradually come on above 45º in altitude and reach its maximum boost directly overhead.  It works best in conjunction with some Climb Gain and can help give a more confident increase in line tension for maneuvers like the overhead figure eight.

The corner boost function is used to add extra RPM when the airplane experiences high g loads in sharp corners.  The altitude that the corner boost is active is restricted to the lower bottom corners of maneuvers only.  It is active when pulling up into a climb and pulling out of a dive for both inside and outside turns.  This boost aids in keeping a more constant velocity throughout the maneuver.

The optimal settings for each parameter are largely a matter of personal preference. That said, there is also a reasonable consensus that the active output could be overused so be careful not to overdo it. Adjustment of the parameters is an experimental process that takes place over several test flights tailored to your particular aircraft and flying style.

One suggested strategy to find your preferred settings is to start with all active functions set to 0.  Adjust the governed RPM setting to yield a lap time that you find the most comfortable.  After that, the next step is to incrementally add Overhead Boost.  When satisfied, then add Climb gain and Dive gain in equal amounts to help maintain a more constant velocity in the maneuvers.  Lastly, add in some corner boost to help reduce the loss of speed in sharp corners.  Finally, go back and re-adjust each parameter, including the governed RPM setting if necessary, to best suit your airplane and flying style.

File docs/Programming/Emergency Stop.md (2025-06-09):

---
title: Emergency Stop
layout: default
parent: Operation
nav_order: 5
---

{% include Header.html %}

## Emergency Stop ##
This is an entirely new concept introduced in v1.5 and I hope users find it helpful.

The traditional control line flight profile ignores the glaring safety concern of the lack of ability to stop the flight at any time when the situation is warranted.  This new E-stop feature allows the pilot to initiate a stop signal to the timer by simply pulling on the control handle three times.  No awkward radio control transmitters or receiver installations are required.

During a “pull” on the control handle the aircraft moves sideways toward the centre of the circle.  During this time the accelerometer reading increases well beyond any reading that occurs during normal acrobatic maneuvers.  Taking advantage of this fact, the timer is programmed to use a form of gesture recognition to identify 3 consecutive pulls on the handle.  When the timer successfully identifies the third pull it will immediately stop the motor.

This is an optional feature and by default is turned **OFF** in the settings.  When turned **OFF** any lateral acceleration of the airplane is ignored.

The physical requirements of the three consecutive pulls are somewhat specific.  Too slow or too fast and the pull may not register and be counted.  To that end, the settings allow for a testing mode.  With the E-stop feature set to **TEST**, the timer will initiate a short *increase* in RPM when it successfully identifies the stop command.  This allows the pilot to learn how the system works and get a feel for the proper timing of the 3 consecutive pulls without having to land, restart and takeoff again.  In this mode the E-stop feature will *not* stop the motor.

When the E-stop feature is fully active in the **ON** position it will stop the motor and terminate the flight when the timer successfully identifies the 3 consecutive pulls.

While primarily intended for emergency use, it can be used to shorten the flight and land at any time.  This could be helpful when training, trimming a new airplane or setting up for a spot landing.

**Helpfull hints:**<br>
The successful activation of the shutdown is very dependent on the pilot movement of the handle.  Some practice may be required to get a feel for the correct timing of the pull sequence.   10-12 inches of travel at the handle should suffice.  All three pulls should occur within 2 to 2 1/2 seconds (approximately 1/3 a circle flying distance).   Most airplanes will yaw back a forth a small amount as it moves inward and then flies back outward.  Initiating the pull sequence downwind is ideal and can aid in helping the airplane fly outward between pulls. **Note:** the E-stop feature is dependent on the timer active output therefore E-stop is not available until 5 seconds after take-off.

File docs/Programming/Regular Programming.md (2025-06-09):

---
title: Regular Programming
layout: default
parent: Operation
nav_order: 2
---

{% include Header.html %}

## Programming Without a Wireless Connection ##

A limited set of programming parameters can also be changed without a Bluetooth connection.  The Delay Time, Flight Time and RPM can be changed as follows:

**Step 1** - 5 taps on the pin to enter the programming mode – the LED will change to yellow (Program Start Delay)

**Step 2** - To move between the three available programming modes:<br>

1 tap for Program Start Delay (yellow)<br>
2 taps for Program Flight Time (cyan)<br>
3 taps for Program RPM (magenta)<br>

**Step 3** - To change a setting while in the programming mode:

*Program Start Delay (yellow):*  Touch and hold the pin.  After a short delay the LED will flash.  Count the number of flashes.  Each flash = 1 second of delay.  Release the pin when you reach the desired count.

*Program Flight Time (cyan):*  Touch and hold the pin.  After a short delay the LED will flash.  Count the number of flashes.  Each flash = 10 seconds of flight time.  Release the pin when you reach the desired count.

*Program RPM (magenta):*

{: .warning }
You are about to run the motor at its flight RPM, secure the aircraft and stay clear of the prop.  The next thing to always remember: **3 TAPS TO STOP THE MOTOR**.

To start the motor, touch and hold the pin.  The LED will flash quickly to warn of the impending start-up.  After a short delay the motor will start and accelerate to the last programmed flight RPM.  Release the pin and the motor will stay running.

While the motor is running:<br>
1 tap on the pin will increase the RPM by 50 RPM.<br>
2 taps will decrease the RPM by 50 RPM.<br>  

Be sure to wait about a second between each set of taps for the RPM to change. Use a tachometer for a more precise setting of the RPM.  Avoid prolonged running on the ground as some electrical components may get hot.

When the desired RPM is reached:<br>
**3 TAPS TO STOP THE MOTOR.**<br>

**Step 4** - 4 taps to exit the programming mode and return to Standby (green).  Any new settings you enter will automatically be saved to memory and used for subsequent flights.

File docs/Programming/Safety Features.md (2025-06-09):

---
title: Safety Features
layout: default
parent: Operation
nav_order: 6
---

{% include Header.html %}

## Built-in Safety Features ##

The timer is programmed to automatically shutdown the motor and jump to the Flight Complete mode if certain fault conditions are detected.  After the motor stops the onboard LED will flash a number of times every 3 seconds to indicate which fault occurred.

{: .warning }
SAFETY FIRST!  While the timer code does include some safety features to help protect the power system, these features do not cover *all* potential problems.  Always use extra caution whenever the battery is connected and something unexpected occurs.

**1 Red Flash**<br>
The motor RPM unexpectedly drops too low.  This can happen if the prop comes in contact with something, i.e. a crash or prop strike, or if the battery voltage drops very low.  This can also occur if there is a poor, or intermittent, electrical connection with the voltage sensing wires to the timer.

**2 Red Flashes**<br>
The motor fails to start properly and/or the timer cannot detect any RPM.  This can happen if there is a poor electrical connection to the ESC or with the voltage sensing wires to the timer. Make sure any ESC "soft start" is OFF.

**3 Red Flashes**<br>
The motor fails to reach the assigned governing RPM.  The motor will operate for a very short period of time but if it cannot attain the desired RPM it will shut down.  This can happen if the battery voltage is too low or if the motor/prop combination is not capable of reaching the set RPM.

{: .highlight}
It is very important to make sure your power system can achieve the desired RPM before programming the timer.

**4 Red Flashes**<br>
At motor start-up the RPM did not increase smoothly. This fault would likely occur because of a nose-over or due to a mechanical issue preventing the motor from rotating.

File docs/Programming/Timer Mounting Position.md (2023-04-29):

---
title: Timer Mounting Position
layout: default
parent: Operation
nav_order: 3
---

## **Climb_and_Dive** ##
{: .text-blue-100}
{: .text-right}

## Programming the Timer Mounting Position ##

### Description ###

The following instructions apply if you would like to install the timer on your airplane in an orientation other than the **default** mounting position described in the [assembly instructions](../Assembly#installation).  If you are using the default mounting position, the timer is already programmed with the default settings and is ready to use.

The programming procedure for this feature is slightly different than the other items in the Bluetooth programming menu so therefore warrant more detailed instructions.  This procedure only needs to be done once after mounting the timer in the airplane, or if you change the timer orientation for any reason.

**Overview**<br>
First, a brief explanation of why this is necessary.  The accelerometer used by the timer actually has (3) separate accelerometers inside.  Each measurement axis is orientated 90 degrees to each other.  In addition, each measurement axis has a positive and negative direction.

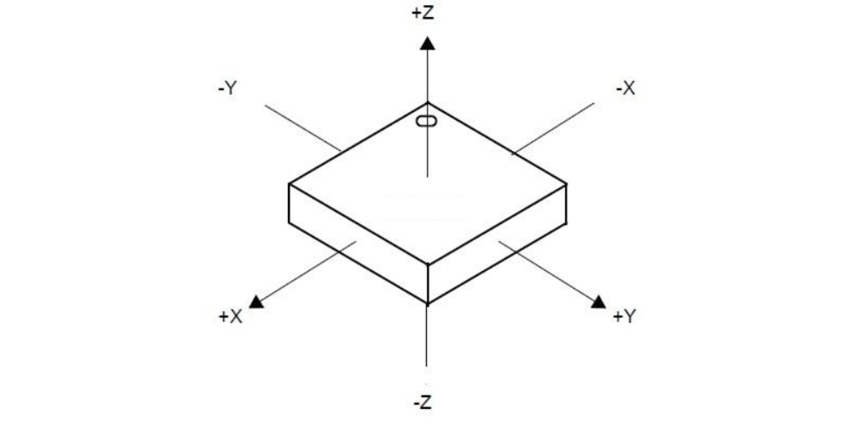
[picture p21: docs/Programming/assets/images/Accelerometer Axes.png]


It is imperative that the timer uses the correct measurement axis and direction for the active output calculations.  If the timer is installed in a different orientation with respect to the wings and fuselage of the airplane, the timer will need to be reprogrammed to tell it which measurement axes to use.

The timer can be installed in any position.  Although, it still must be installed so that the sides and edges of the timer are aligned with the major axes of the airplane.  The timer *cannot* be mounted askew, tilted or at an angle to the wing and fuselage axes.

**Programming**<br>
Programming the timer to tell it which accelerometer axes to use is a two step process.  

{: .highlight }
Safety first: You are about to connect the battery to power-up the airplane.  Although you will only enter the Bluetooth programming mode, for maximum safety remove the propeller or get someone to securely hold the airplane at all times.

With the timer installed in the airplane, power it up and enter the Bluetooth programming mode.  From the menu selections choose the Mounting Position option.

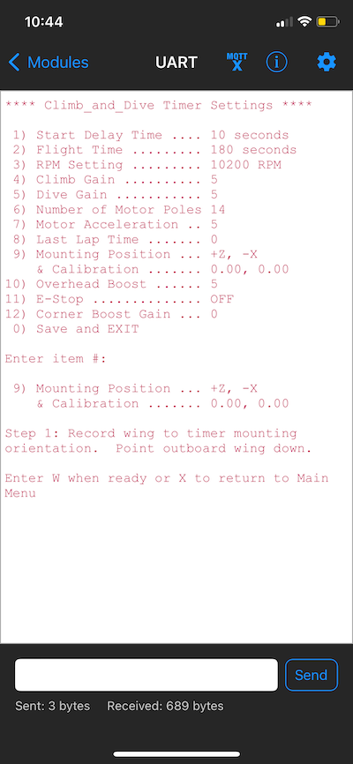
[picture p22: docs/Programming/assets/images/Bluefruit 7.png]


**Step 1**<br>
Follow the onscreen prompt and hold the airplane with the outboard wing pointing down (leadouts pointing up to the sky).  When you are ready, enter the letter "W" to tell the timer this is the accelerometer axis you want to use for the wing axis.  There is also an option to enter "X" if you want to exit the procedure and return to the main menu without making and changes.

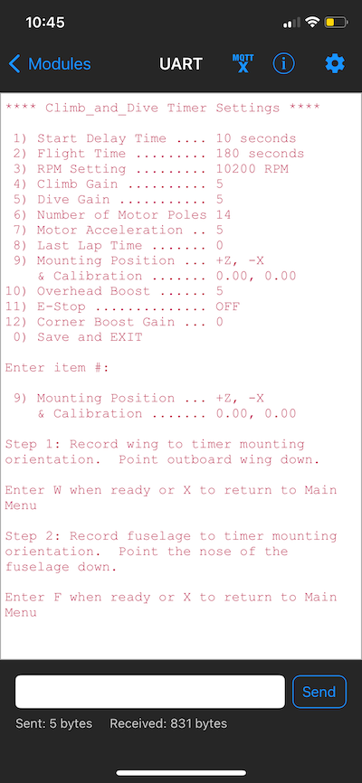
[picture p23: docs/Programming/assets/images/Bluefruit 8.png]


**Step 2**<br>
Next, the prompt will ask you to rotate the airplane so that the fuselage is vertical with the nose pointed down and the rudder pointing up to the sky.  When you are ready, enter the letter "F" to tell the timer this is the accelerometer axis you want to use for the fuselage axis.  Again, there is also an option to enter "X" if you want to exit the procedure and return to the main menu without making any changes.

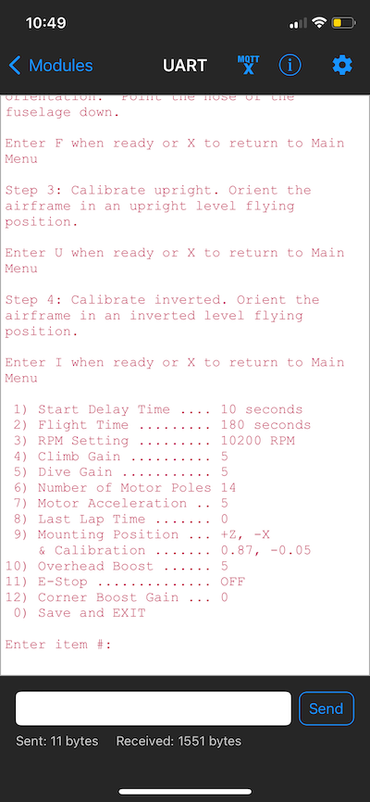
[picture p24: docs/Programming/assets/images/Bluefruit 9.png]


**Results**<br>
The menu will reappear showing the new accelerometer axes assigned to the airplanes wing and fuselage axes.  The **default orientation** of the timer uses the +Z axis assigned to the wing axis and the -X axis assigned to the fuselage axis.  All other mounting orientations will use a different combination of axes and signs.

Be sure to **save** the new programming settings when you disconnect and exit the Bluetooth programming mode.

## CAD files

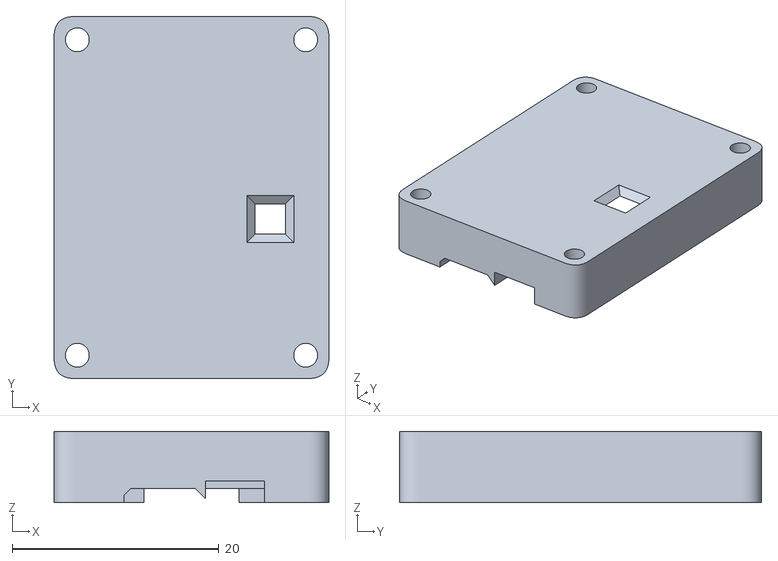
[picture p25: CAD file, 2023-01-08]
Design Files/Casing/Case Top.stl
26.6 x 35.0 x 6.91

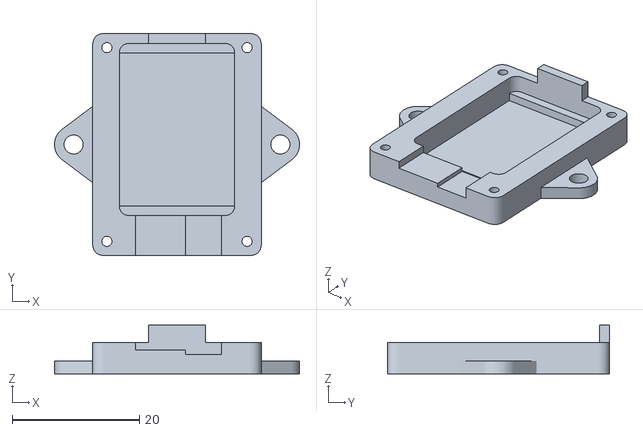
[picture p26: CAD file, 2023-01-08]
Design Files/Casing/Case Bottom.stl
38.6 x 35.0 x 7.70

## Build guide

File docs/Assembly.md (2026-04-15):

---
title: Assembly
layout: default
nav_order: 2
---

{% include Header.html %}

## Bill of Materials ##

Complete project kits can be purchased on [**Lectronz**][12].  Most users choose to order a fully assembled timer.  The following instructions are provided if you want to assemble your own for maximum customization. All kits come complete with the program code already installed and the circuit boards fully tested.

If you prefer to purchase items separately here are some suggested sources:

| Qty | Description | Online Sources |
| :---: | --- | --- |
| 1 | Seeed Studio Xiao nRF52840<br>(The cheaper one, not the 'Sense' version) | [Digikey][9]<br>[Mouser][10]<br>[Seeed Studio][11]  |
| 1 | Climb_and_Dive Backpack w/ 5 pin RA Header Strip| [Lectronz][3] |
| 1 | JST Battery Connector (Optional) | [HobbyTown][7]<br>[Amazon][8] |

## Tools Required ##

Electronic soldering equipment; soldering iron, flux and solder.  These are available from numerous sources online.  If you need to brush-up on your electronics soldering skills there are some good tutorials on [Adafruit][1] and [Sparkfun][2].  You will also need a set of diagonal pliers or wire cutters and a small spring clamp.

{: .warning }
Do **not** use a strong acid based flux.  While this type of flux is great for home plumbing repairs and building fuel tanks, it can be very corrosive to fragile electronic circuitry. Be sure to only use a [rosin based][5] or [no-clean  type][4] flux suitable for electronics assembly.

## Timer Assembly ##

The boards as supplied include strips of breakaway header pins.  Assemble and solder as shown in the photos below.  Be careful to orient the boards correctly.  The USB C port must be on the end opposite the ESC/Motor connection pins.

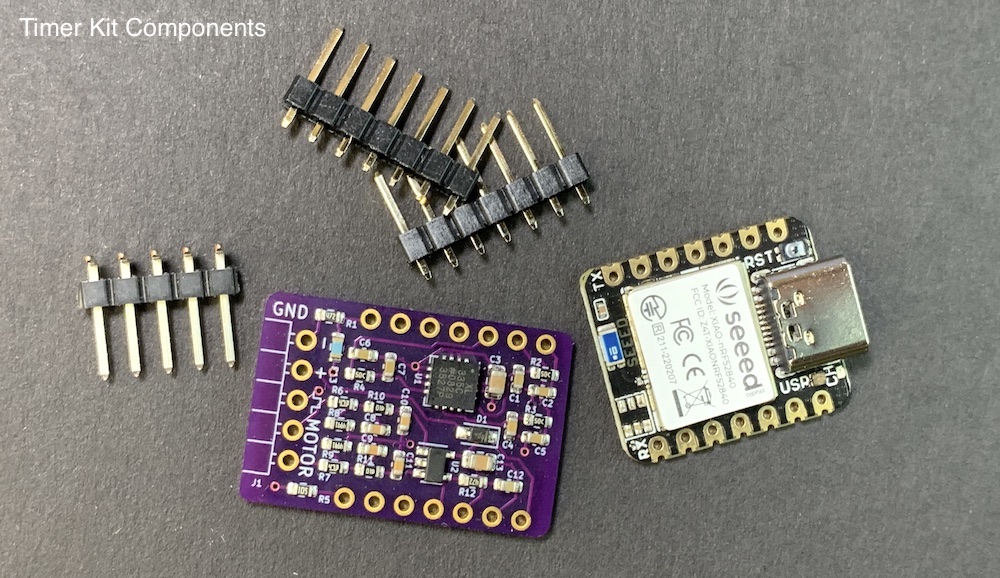
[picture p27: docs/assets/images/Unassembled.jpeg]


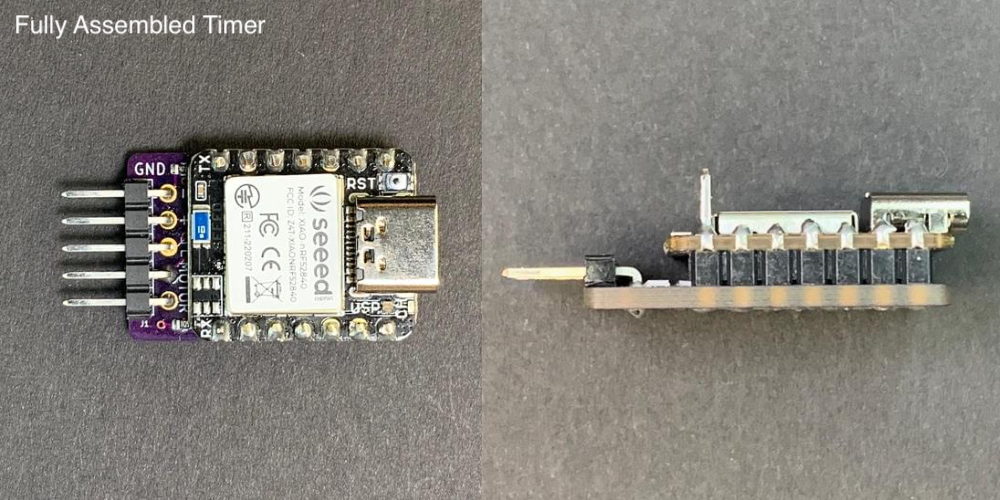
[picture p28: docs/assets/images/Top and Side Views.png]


---
**Step 1** - Insert the bent legs of the 5 pin right angle strip through the backpack PCB and hold with a clamp for soldering.

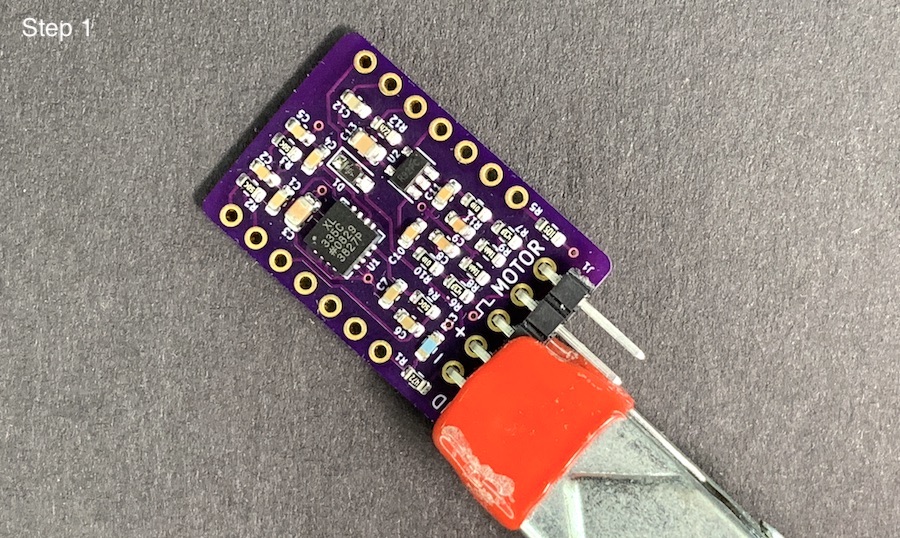
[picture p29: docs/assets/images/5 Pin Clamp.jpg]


___
**Step 2** - Solder the pins to the back side of the backpack as shown.

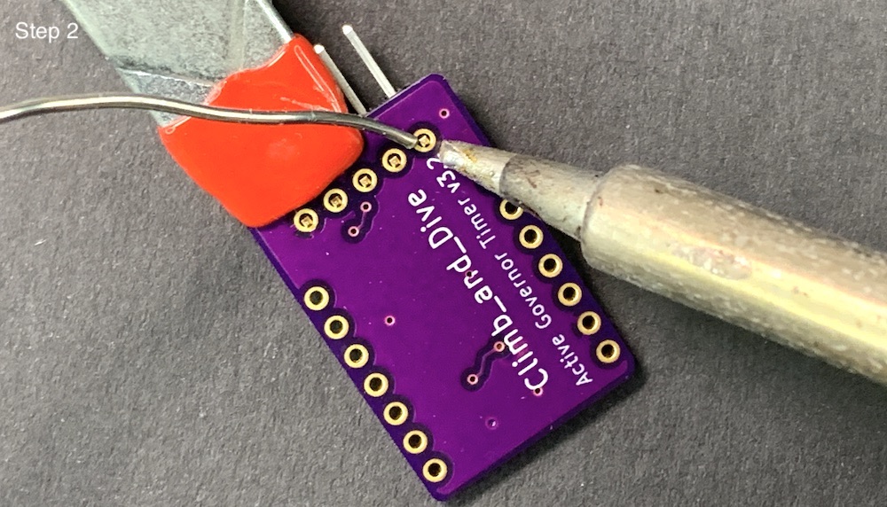
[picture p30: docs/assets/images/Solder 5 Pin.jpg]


___
**Step 3** - Insert the short legs of the 7 pin header strips through the holes on the top of the backpack.  Then stack the Xiao on top of the long pins and clamp together for soldering.  Make sure it is orientated as shown.

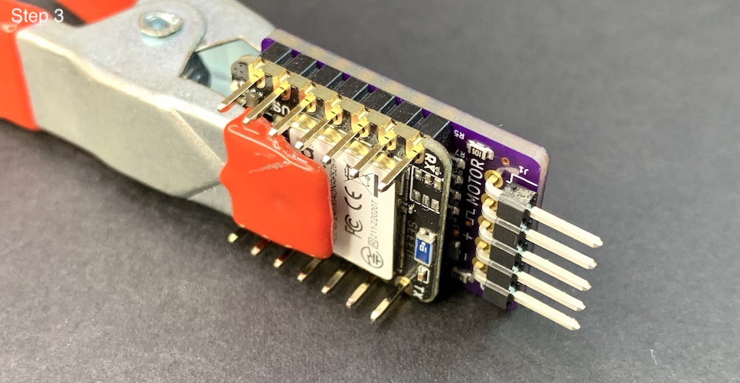
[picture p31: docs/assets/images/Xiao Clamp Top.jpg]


___
**Step 4** - Solder all of the short header pins on the back of the backpack.

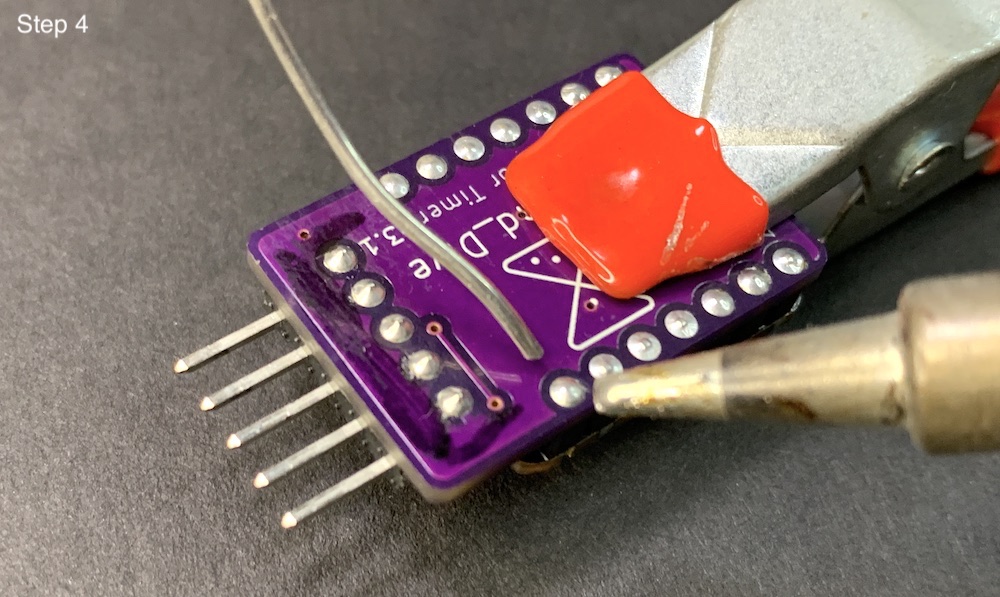
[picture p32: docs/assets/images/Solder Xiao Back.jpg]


___
**Step 5** - Flip it over and solder all of the longer header pins on the Xiao nRF52840.  Don't trim the long pins just yet.

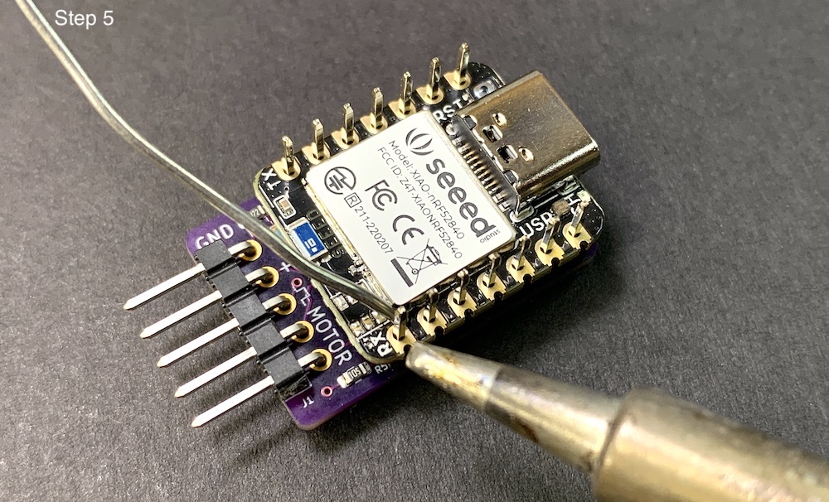
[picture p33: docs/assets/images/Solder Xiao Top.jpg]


___
**Step 6** - At this point you can trim off *only* the long header pins that you *don't* need.  You have some choices to make.  First off, do **not** cut the touch pin, leave it sticking out.

Next, decide if you would like to add an *optional* push-button switch to use instead of the touch pin.  The push-button switch connects to two timer pins. Depending how you want to connect your switch, you may want to leave those two pins sticking out as it makes connecting the switch much easier.  The push-button switch functions exactly the same as the touch pin.  Note: you must use a **normally open (NO) momentary contact type switch**.  The touch pin will remain usable and works in parallel with the push-button switch. A push-button switch connects to the timer using the 2 pins as shown below.

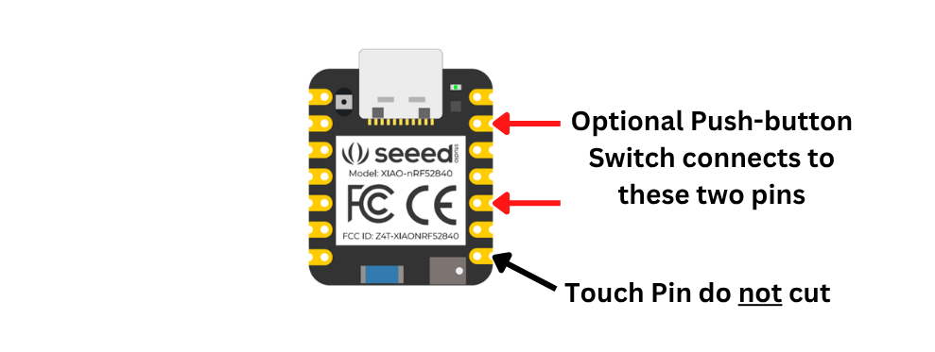
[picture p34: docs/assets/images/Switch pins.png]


Next, decide if you would like to add an *optional* remotely mounted addressable LED status indicator light.  See the [**Advanced Modifications**][13] page for details. An addressable LED uses three timer pins.  Again, leaving these pins sticking out can make future connections much easier.  An LED connects to the timer using the 3 pins as shown below.

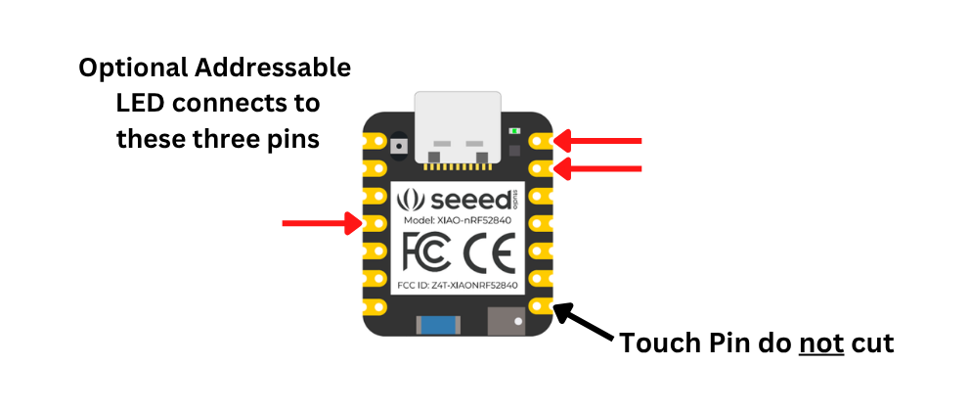
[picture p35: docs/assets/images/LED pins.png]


I recommend that you leave *all* options available. In that case, you need to leave all 5 pins untrimmed as shown below.  This configuration is the best for attaching the accessory <a href="https://circuitflyer.com/Control_Panel/" target="_blank" rel="noopener noreferrer">**Control_Panel** </a> remote interface.

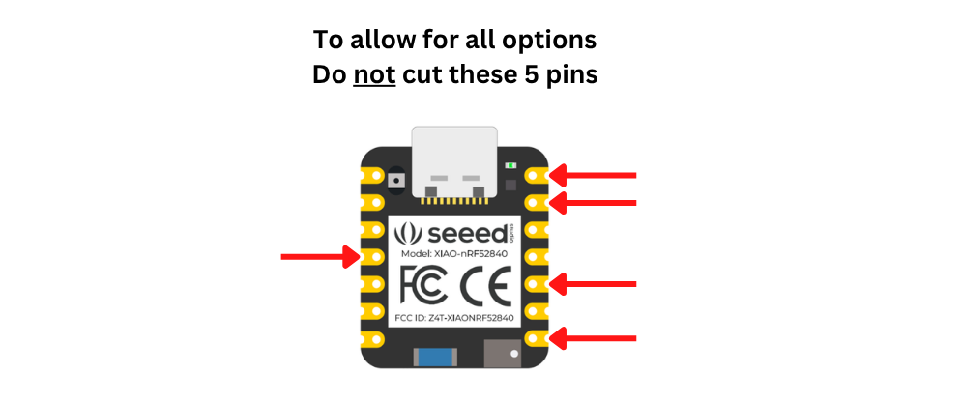
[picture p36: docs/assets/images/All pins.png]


___
**Step 7** - Optional: It's a good practice to remove any residual solder flux from the joints. You can do this by using an old toothbrush dipped in 99% Isopropyl alcohol, gently scrubbing away the remaining flux. This high-concentration alcohol is readily available at your local drug store.

[1]: https://learn.adafruit.com/adafruit-guide-excellent-soldering
[2]: https://learn.sparkfun.com/tutorials/how-to-solder-through-hole-soldering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
[3]: https://lectronz.com/products/climb_and_dive
[4]: https://www.chipquik.com/store/product_info.php?products_id=330003
[5]: https://www.chipquik.com/store/product_info.php?products_id=310027
[7]: https://www.hobbytown.com/protek-rc-jst-male-connector-leads-2-ptk-5218/p23432
[8]: https://www.amazon.com/Silicone-Connector-SIM-NAT-Connectors/dp/B071XN7C43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
[9]: https://www.digikey.com/en/products/detail/seeed-technology-co-ltd/102010448/16652893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
[10]: https://www.mouser.com/ProductDetail/Seeed-Studio/102010448?qs=Znm5pLBrcAJ5g%252BWAkitg4w%3D%3D
[11]: https://www.seeedstudio.com/Seeed-XIAO-BLE-nRF52840-p-5201.html
[12]: https://lectronz.com/products/climb_and_dive
[13]: http://127.0.0.1:4000/docs/Advanced%20Modifications.html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

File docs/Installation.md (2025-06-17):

---
title: Installation
layout: default
nav_order: 3
---

{% include Header.html %}

## Installation ##

The flat bottom of the timer is intended be installed on a vertical part of the aircraft with the ESC/Motor connection pins pointing forward and the component side of the timer facing the pilot.  Although not super-critical, it is important that the long side of the timer is installed so that it is horizontal when the aircraft is flying straight and level.

{: .highlight }
The description above is considered the **default** mounting orientation.  Installing the timer in your airplane in a different orientation is permissible. Please refer to the page titled [Timer Mounting Position & Calibration](Programming/Timer Mounting Position & Calibration) for details.

A couple of pieces of adhesive backed hook and loop fastener (aka Velcro) makes quick work of holding the timer in position.

Please keep in mind that the accelerometer is a very sensitive device and excessive vibration can make it difficult to get accurate readings.  If possible locate the timer away from any source of vibration.  It's always a good idea to balance new propellers before use.

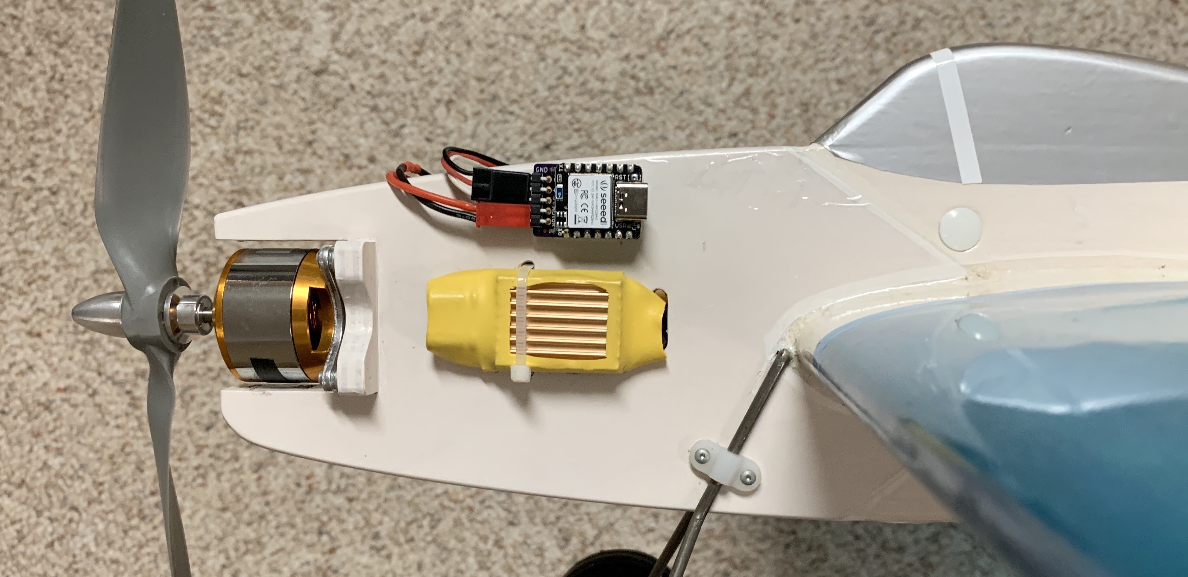
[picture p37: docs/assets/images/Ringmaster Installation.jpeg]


## Connecting it All Together ##

{: .highlight }
When connecting the ESC servo connector be sure the **ground wire (brown or black)** is attached to the ground pin on the board, labeled **GND**.  

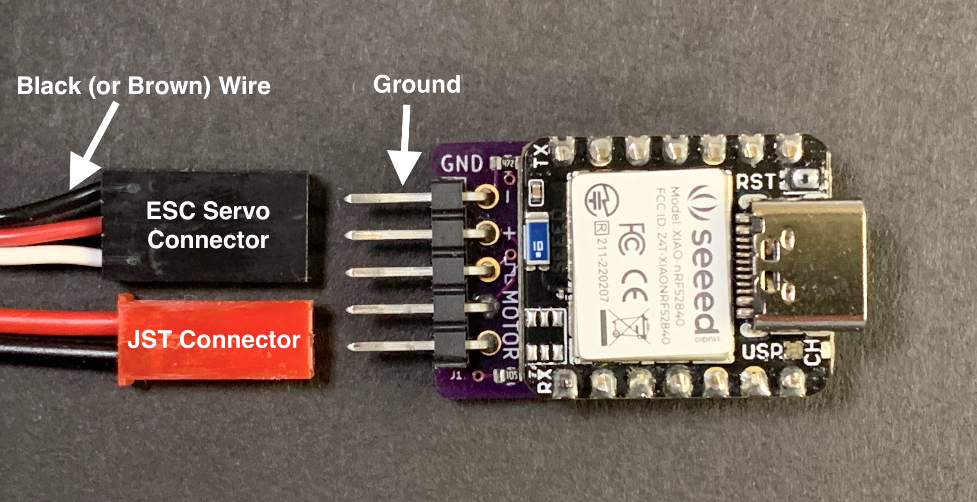
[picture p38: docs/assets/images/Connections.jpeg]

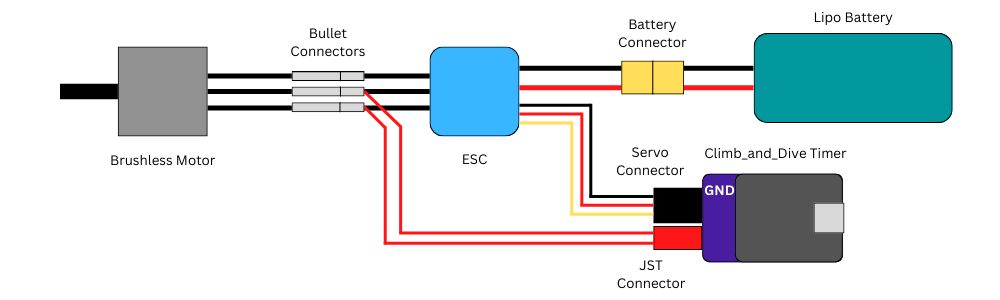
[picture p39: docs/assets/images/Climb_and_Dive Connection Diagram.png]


Connect the backpack motor pins to any two of the three motor wires.  It doesn't matter which two.  For convenience I use a male JST battery style connector (just for reference: the full manufacturers name is a male JST-RYC connector).  Solder the JST connector leads into the back of the bullet connectors of the ESC motor wires.

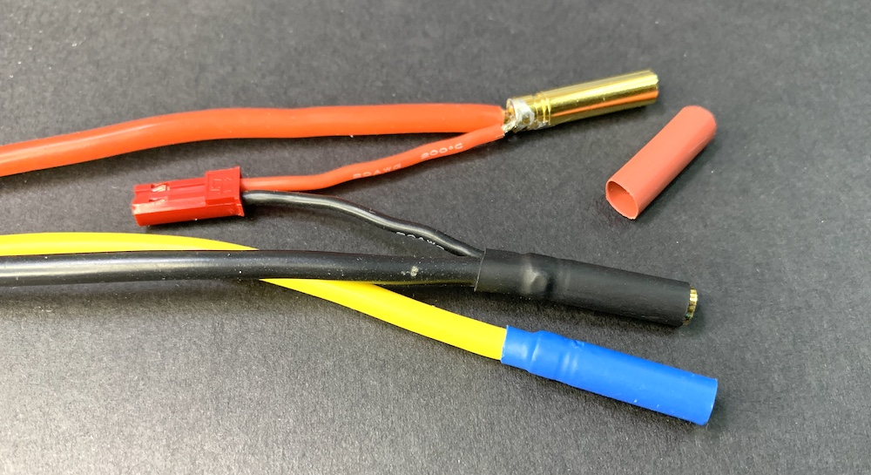
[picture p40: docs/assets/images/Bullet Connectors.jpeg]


{: .highlight }
Note: The main reason a JST connector is suggested is only because it's a very common 2-pin connector available from just about any hobby shop.  It may not be the ideal connector if connected and disconnected frequently.  A more robust connector would be a 2-pin "Dupont" connector.  Unfortunately, these are a little harder to find but are available from online retailers.

## Optional Modifications ##

The following items are not necessary for normal operation of the timer.  They are listed here only as additional information that may pertain to your particular installation requirements.

**Touch Pin Options**

The touch sensor pin works by sensing a change in capacitance of the exposed header pin.  The conductivity of everyones fingertip is a little different and in some cases you may find the touch the sensor pin does not working reliably to your satisfaction.  The small pin limits the surface area in contact with your fingertip.

The best way to increase the sensitivity of the pin is to increase the contact surface area of the 'sensor'.

One simple method to increase the area is to apply a short pieces of electrically conductive tape to the exterior of the airplane.  A length of wire can then be used to connect the timer sensor pin to the conductive tape.  The increased area of the conductive tape greatly improves the operation of the touch sensor.  The exposed tape is the most sensitive but, at the cost of a slight reduction in sensitivity the tape can be hidden underneath iron on covering, paint, dope or a thin vinyl decal and it still works!  This option works great for airplanes with a full body fuselage.

Adafruit has both flexible [nylon conductive tape][1] and not so flexible [copper conductive tape][2]. A search on Amazon for conductive cloth tape, conductive nylon adhesive tape or faraday cloth tape also turned up several suitable choices.  The adhesive is also conductive so connecting the wire is as easy as applying the tape over the striped end of the wire.  A female servo connector pin crimped onto the other end of the wire allows for a removable connection to the timer touch sensor pin.

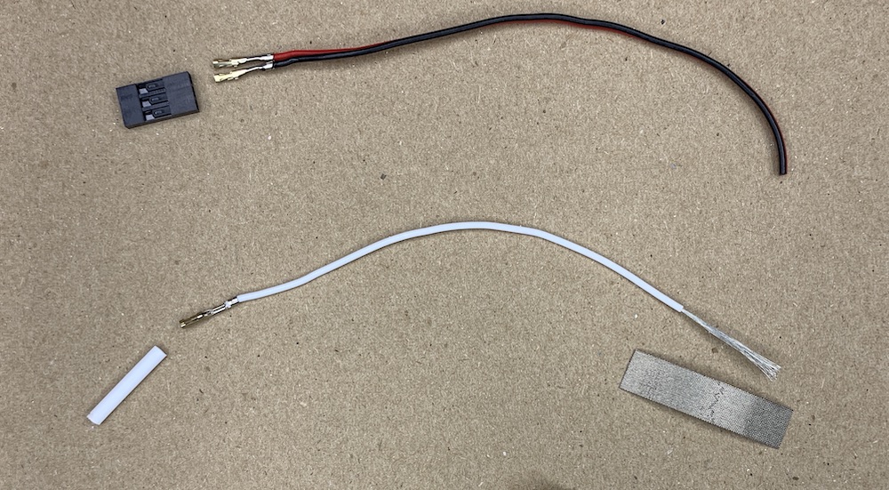
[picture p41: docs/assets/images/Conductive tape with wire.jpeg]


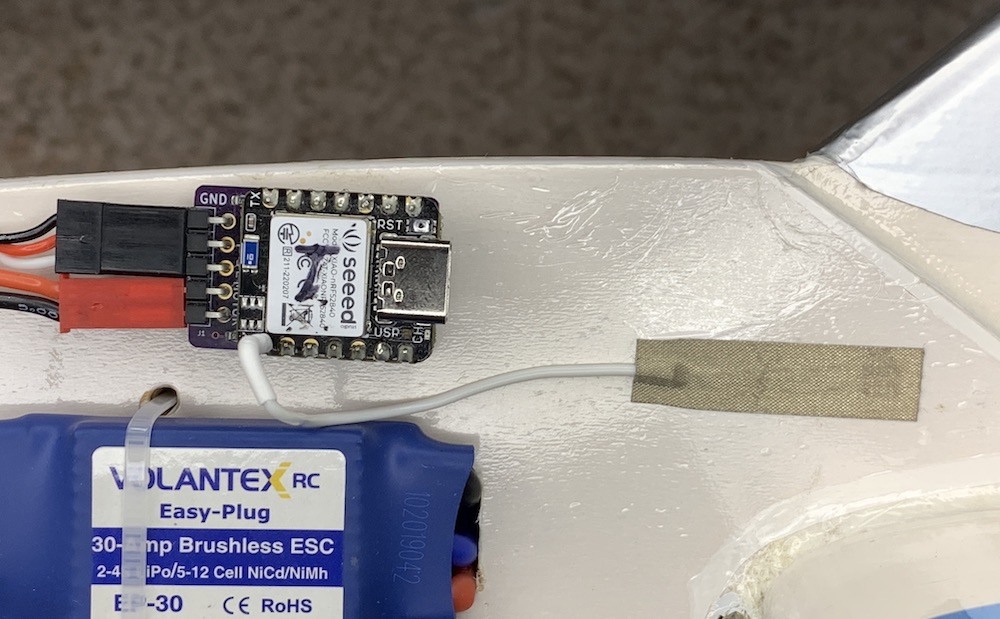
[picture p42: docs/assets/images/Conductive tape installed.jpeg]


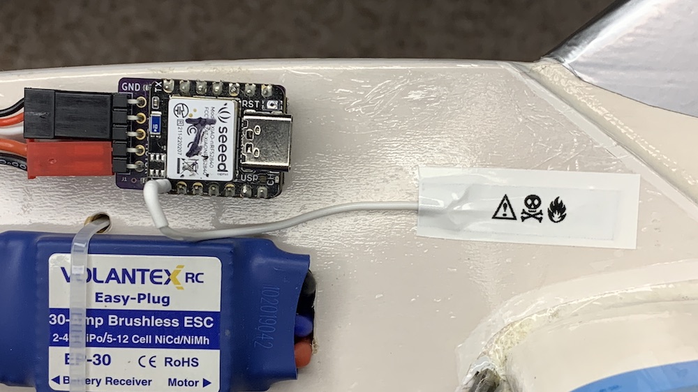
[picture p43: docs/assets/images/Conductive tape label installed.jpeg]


[1]: https://www.adafruit.com/product/3960
[2]: https://www.adafruit.com/product/3483

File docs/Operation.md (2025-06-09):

---
title: Operation
layout: default
nav_order: 7
has_children: true
---

{% include Header.html %}

## Operating Instructions ##

Install the timer and connect to the ESC as discussed in the assembly instructions.

The tri-colour LED is used to communicate the different modes of operation.  The touch sensitive pin is used for operator input.  This is similar to the touch sensitive screen on a smart-phone.  (Hint: As the conductivity of the average fingertip can vary, adding a bit of moisture to your fingertip will greatly improve the touch response.)

A long touch is a sustained touch for a minimum of 3 seconds.  A tap, or series of taps, is a single or multiple quick taps on the pin.  You will notice a 1 second delay after the last tap before the desired action takes place.  This short waiting period is needed to make sure all of the taps are complete.

When you connect the battery to the ESC the timer will boot up and the tri-colour LED will turn green (Standby Mode).  At this point the board will output an “idle” signal to the ESC.  The ESC should complete its initialization and arming sequence.
The very first time the board is powered up it will load the default settings.

To change any of the programmable settings please refer to the Bluetooth programming section.

{: .warning }
SAFETY FIRST!  Any time the battery is connected stay clear of the prop.  The aircraft should always be held or secured until the pilot is ready.  When the flight ends the pilot should wait until his/her helper disconnects the battery before putting the handle down.

When ready, touch and hold the pin (a long touch of a minimum of 3 seconds), the motor will spin up at a low RPM for half a second (red LED) and then stop.  This short throttle 'blip' indicates the start of the flight sequence.  The timer will now be in the Start Delay mode (flashing blue).  This indicates the start of the countdown timer before the motor starts.  During the last 5 seconds of the countdown the LED will change to white and flash quickly to warn of the impending startup of the motor.

{: .highlight }
Note: Any touch of the pin during the Start Delay mode will stop the countdown and return to the Standby mode (green).

After the Start Delay the Flight mode will start (flashing red) and the motor RPM will slowly increase to the desired flight RPM at the programmed rate.  This will assist with a smooth take-off.  In oder to allow for a smooth climb to cruising speed there is a 5 second delay before the active function of the timer becomes fully operational.

{: .highlight }
If you need to abort the flight: After the motor starts, **any touch of the pin will stop the motor** and jump to the Flight Complete mode (LED off).

10 seconds before the Flight mode is complete the LED will quickly flash white to indicate the end of the flight.  The motor RPM will then increase for 3 seconds before stopping to aid in a smooth approach and landing.  There is also and option to add up to 10 seconds of normal flight RPM *after* the 3 second burst of high RPM to allow extra time to prepare for the landing.  Once the motor stops the program enters the Flight Complete mode (LED off).  The power must be reset in order to exit the Flight Complete mode.

Disconnect the battery, replace it with a fully charged one and repeat the process for the next flight.

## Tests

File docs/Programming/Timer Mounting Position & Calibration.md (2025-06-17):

---
title: Timer Mounting Position & Calibration
layout: default
parent: Operation
nav_order: 3
---

{% include Header.html %}

## Programming the Timer Mounting Position & Calibration ##

### Description ###

{: .highlight }
**New for v1.5** - The following instructions have been revised to include additional steps to calibrate the accelerometer.  **Before you can program the new Corner Boost feature the Mounting Position & Calibration procedure must be completed.**

The following instructions needs to be completed after mounting the timer in the airplane, *or* if you change the timer orientation for any reason. Even if you have installed the timer on your airplane in the **default** mounting position, this procedure is still necessary in order to complete the calibration sequence. Although this procedure only needs to be completed once, it can be repeated if necessary.

The programming procedure for this feature is slightly different than the other items in the Bluetooth programming menu so therefore warrant more detailed instructions.  

**Overview**<br>
First, a brief explanation of why this is necessary.  The accelerometer used by the timer has (3) separate accelerometers inside.  Each measurement axis is orientated 90 degrees to each other.  In addition, each measurement axis has a positive and negative direction.



It is imperative that the timer uses the correct measurement axis and direction for the active output calculations.  If the timer is installed in a different orientation with respect to the wings and fuselage of the airplane, the timer will need to be reprogrammed to tell it which measurement axes to use.

The timer can be installed in any position.  Although, it still must be installed so that the sides and edges of the timer are aligned with the major axes of the airplane.  The timer *cannot* be mounted askew, tilted or at an angle to the wing and fuselage axes.

The accelerometer provided on the timer circuitboard will have some inherent discrepancies with known conditions.  The basic two point calibration procedure described here will allow the timer to automatically calculate the scale factor and the offset necessary to correct for any discrepancy.

**Programming**<br>
Programming the timer for both mounting position and calibration is a four step process.  

{: .highlight }
Safety first: You are about to connect the battery to power-up the airplane.  Although you will only enter the Bluetooth programming mode, for maximum safety remove the propeller or get someone to securely hold the airplane at all times.

With the timer installed in the airplane, power it up and enter the Bluetooth programming mode.  From the menu selections choose the Mounting Position & Calibration option.



**Step 1**<br>
Follow the onscreen prompt and hold the airplane with the outboard wing pointing down (leadouts pointing up to the sky).  When you are ready, enter the letter "W" to tell the timer this is the accelerometer axis you want to use for the wing axis.  There is also an option to enter "X" if you want to exit the procedure and return to the main menu without making and changes.



**Step 2**<br>
Next, the prompt will ask you to rotate the airplane so that the fuselage is vertical with the nose pointed down and the rudder pointing up to the sky.  When you are ready, enter the letter "F" to tell the timer this is the accelerometer axis you want to use for the fuselage axis.  Again, there is also an option to enter "X" if you want to exit the procedure and return to the main menu without making any changes.

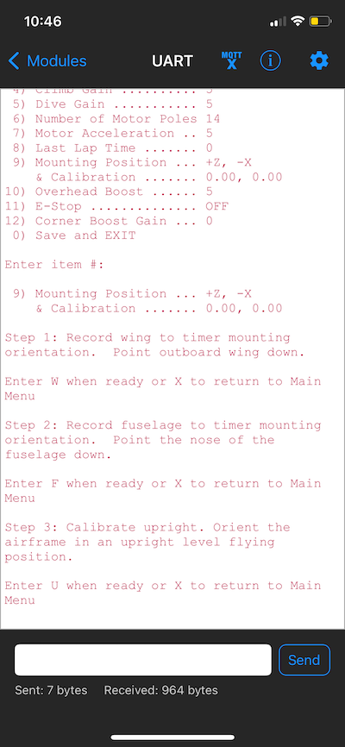
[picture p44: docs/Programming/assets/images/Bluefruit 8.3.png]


**Step 3**<br>
Next, the prompt will ask you to rotate the airplane so that both the wings and fuselage are level in an upright normal flying attitude. Note: this does not have to be precise, within a few degrees of level should suffice. When you are ready, enter the letter “U” to tell the timer to record a reading in this position. Note: the model must be held steady and not moving while it reads the sensor.  Again, there is also an option to enter “X” if you want to exit the procedure and return to the main menu without making any further changes

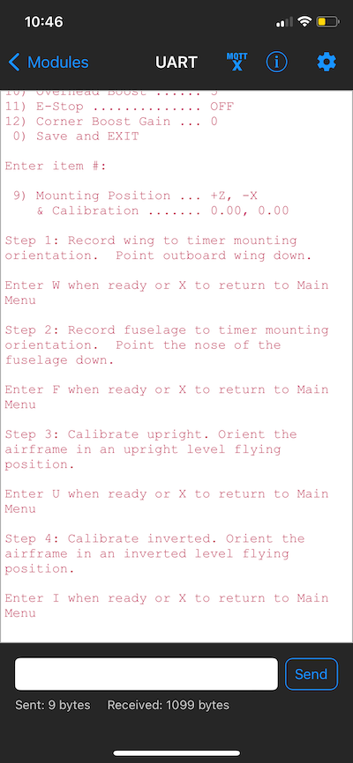
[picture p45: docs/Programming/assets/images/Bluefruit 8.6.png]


**Step 4**<br>
Finally, the prompt will ask you to rotate the airplane so that both the wings and fuselage are level in an inverted upside down flying attitude. Note: this does not have to be precise, within a few degrees of level should suffice. When you are ready, enter the letter “I” (capital i) to tell the timer to record a reading in this position. Note: the model must be held steady and not moving while it reads the sensor.  Again, there is also an option to enter “X” if you want to exit the procedure and return to the main menu without making any further changes



**Results**<br>
The menu will reappear showing the accelerometer axes assigned to the airplanes wing and fuselage axes.  The **default orientation** of the timer uses the +Z axis assigned to the wing axis and the -X axis assigned to the fuselage axis.  All other mounting orientations will use a different combination of axes and signs.

The Calibration results will be displayed as two numbers.  The first number will be used as the scale factor to correct for any slope errors.  The second number is used to offset the accelerometer readings so that they centre around 0.  Each particular timer and installation will use different values.

Be sure to **save** the new programming settings when you disconnect and exit the Bluetooth programming mode.

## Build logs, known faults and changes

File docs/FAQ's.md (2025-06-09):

---
title: FAQ's
layout: default
nav_order: 9
---

{% include Header.html %}

## Frequently Asked Questions ##

**Does the Climb_and_Dive work with any ESC?**  If the ESC works well with a servo tester I don't see any reason why it shouldn't work with the timer.  The timer does require an ESC with a built in BEC (battery eliminator circuit).  Ideally, the ESC should have a means to calibrate the throttle to match the timer output range.  It will not work with ESC's that require a mandatory maximum throttle signal in order to complete the throttle calibration sequence prior to each and every flight.  Castle Creations Phoenix line of ESC's are a special case and more information can be found [here](Power%20System%20Information.html#castle-creations).

**Can I extend the touch sensor pin?**  Yes, you can.  You will have to experiment to make sure it works reliably, but you can add a wire to the touch sensor pin to extend the ‘sensor’ to another location.  See [Optional Modifications](Installation.html#optional-modifications) for more information.

**Why don't I get the short throttle 'blip' when I start the timer?**  If your ESC has a procedure for throttle calibration, try that, it may help.  See [ESC Information](Power System Information#ESC Information).  Also make sure any soft start feature in the ESC is set to fast or hard start.

**The motor takes to long to get to cruising speed after take-off**  Do not hold the running airplane for an extended period before releasing for take-off.  There is a 5 second delay after the motor reaches the programmed flight RPM until the active function of the timer becomes fully operational.  This is to prevent the active function from impeding the airplane climb-out and acceleration to cruising speed.

**Why can't I enter a setting for Corner Boost?**  A complete [Timer Mounting Position & Calibration](Programming/Timer%20Mounting%20Position%20&%20Calibration.html) routine must be completed before Corner Boost can be used.

**Is a Bluetooth wireless connection allowed in competition?**  The Bluetooth radio is turned on *only* while the timer is in the programming mode.  Therefore the Bluetooth connection cannot be construed as to provide any control of the aircraft during flight.  Bluetooth is 2.4GHz spread spectrum technology.  The timer uses low energy Bluetooth transmitted through a very small onboard antenna which limits its useful range to about 30 feet, or 10 meters, maximum.

**Is Bluefruit Connect the only app that will work with the timer?**  No, there are other free Bluetooth apps that support wireless UART communication.  Bluefruit Connect is suggested for its simplicity and ease of use.

**Can I make a housing for the timer to help protect it?**  Of course, but making it completely weatherproof may be a challenge.  If you have access to a 3D printer you can download STL files for a casing and cover [here][4].

**What type of solder do you use for the backpack PCB assembly?**  The backpack components are soldered with a RoHS compliant lead-free synthetic no-clean formula solder paste.

**What is bootout.txt on the `CIRCUITPY` drive?**  This a small text file that is automatically generated by CircuitPython.  It includes information on which version of CircuitPython is installed as well as details about the microcontroller board.

**What version of the program code do I have installed?** The software version is included in the device name that appears on the Bluetooth app window when you connect to the timer.

**What is CircuitPython?**  CircuitPython is Adafruit's fork of the MicroPython programming language.  Micropython is a subset of instructions derived from Python specifically for use on microcontrollers.  CircuitPython is well supported and a tonne of information can be found in various [Adafruit learning guides][2].

**Can I make changes to the program code?**  Yes, Adafruit and CircuitPython make it easy.  If you are making minor changes, open code.py in any text editor program, like Notebook or TextEdit.  Make your changes and then save it as code.py back onto the `CIRCUITPY` drive.  As soon as the code is saved the program re-boots and your new code starts running.  If you would like to make more substantial changes then I would suggest a free code editing program like [Mu Editor][1].  The [Adafruit Learning Guides][3] cover everything you need to know.

[1]: https://codewith.mu/en/about
[2]: https://learn.adafruit.com/welcome-to-circuitpython
[3]: https://learn.adafruit.com/welcome-to-circuitpython/creating-and-editing-code
[4]: https://github.com/CircuitFlyer/Climb_and_Dive/tree/main/Design%20Files/Casing

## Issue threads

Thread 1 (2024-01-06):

RPM feedback-  A question

ne9n, 2024-01-06:
First of all nicely done! I have been working for over 30 years in industrial motor control, power tool control, and now lawn equipment.    I have my own Arduino-based pitch controller that I have developed.  I never really got it past prototype.   Mine is all feed-forward and uses the MPU 6050 and SPI and no active feedback.

Do I understand it correctly that the RPM feedback is filtered so you get a single pulse per electrical cycle?

Do you work about high S counts and motor back EMF damaging the comparator?

CircuitFlyer, 2024-01-06:
Thank you.  I'm no embedded systems expert, just a hack that cobbled together the necessary parts to make it work reasonably well.

Yes, the RPM signal conditioning circuit outputs a single pulse per electrical cycle, electrical RPM per se.

The circuit contains a resistor divider to initially lower the motor winding voltage.  The RC filtering further attenuates the signal voltage feed to the comparator.   It should be able to handle 2S up to 8S lipo batteries.  That seems to be the practical limit of the batteries currently used in control line.

ne9n, 2024-01-06:
I might suggest some clamping diodes or tvs diodes to clamp the max
voltage.  I can sketch it up if you like.

On Sat, Jan 6, 2024 at 9:34 AM CircuitFlyer ***@***.***>
wrote:

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

CircuitFlyer, 2024-01-07:
Of course, any suggestions to help better protect the circuitry would be welcome.

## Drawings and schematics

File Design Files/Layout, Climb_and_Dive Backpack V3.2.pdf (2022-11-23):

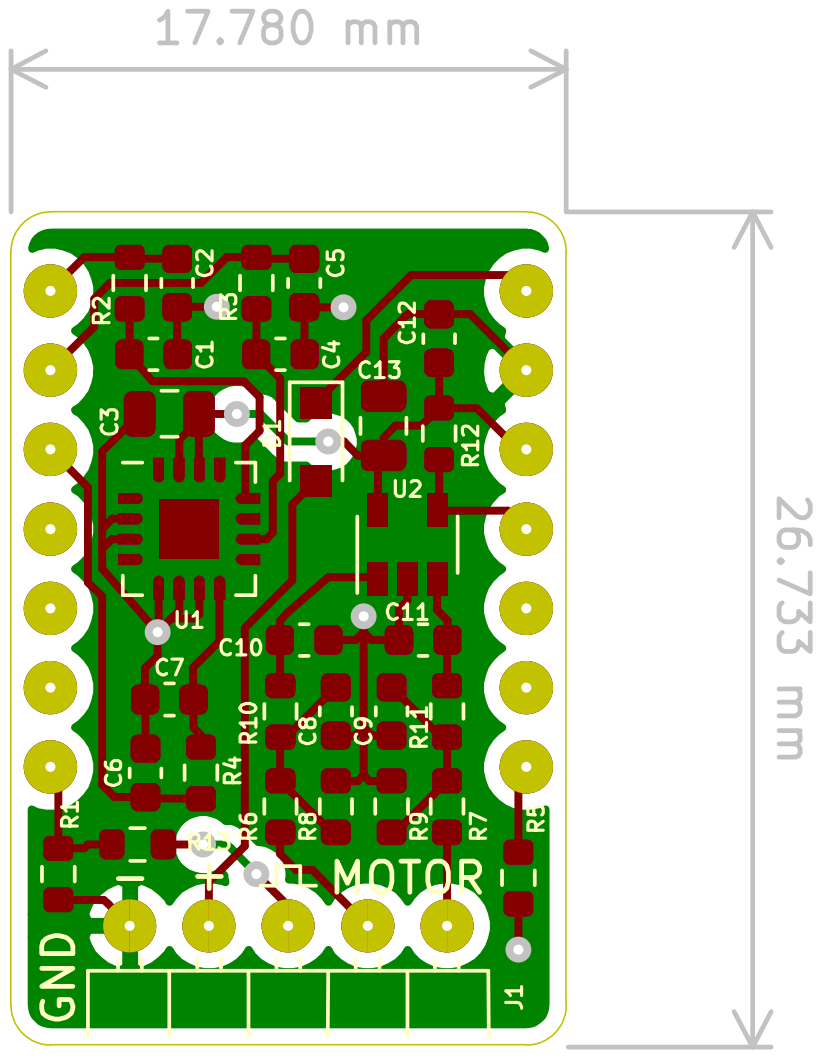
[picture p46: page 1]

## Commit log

2022-11-11 Update Power System Information.md
2023-02-14 Update Schematic, Climb_and_Dive Backpack, V3.2.pdf
2023-04-09 Schematic Revision, 3.2.1
2023-11-20 Schematic Revised
    Backpack schematic updated to v3.2.2
2024-01-06 Added Additional Information
    Castle Creations ESC set-up & notes on improving touch sensor operation
2024-01-13 Update Power System Information.md
    Added note for Castle ICE ESC's
2024-01-14 Update Power System Information.md
    Grammer correction
2024-05-14 Update Assembly.md
    Add warning regarding acid based flux
2025-06-17 Revised calibration instructions
2025-08-09 Remove Schematic
    Temporarily remove schematic for revision/update
2026-06-14 Update instructions to v1.5.3
    Update to v1.5.3 - increase motor pole count from 24 to 28
